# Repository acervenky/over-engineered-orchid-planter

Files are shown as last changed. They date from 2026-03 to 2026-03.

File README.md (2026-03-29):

<div align="center">

# 🌸 Smart Tolumnia Planter V1

### *The Unnecessarily Intelligent Epiphyte Bioreactor*

An intelligent, two-tiered 3D-printed enclosure with an **autonomous Qwen-powered AI agent** that perfectly orchestrates the strict flood-and-bone-dry cycles required by bare-root Tolumnia orchids... because watering plants with a spray bottle is *so* last century.

<br>
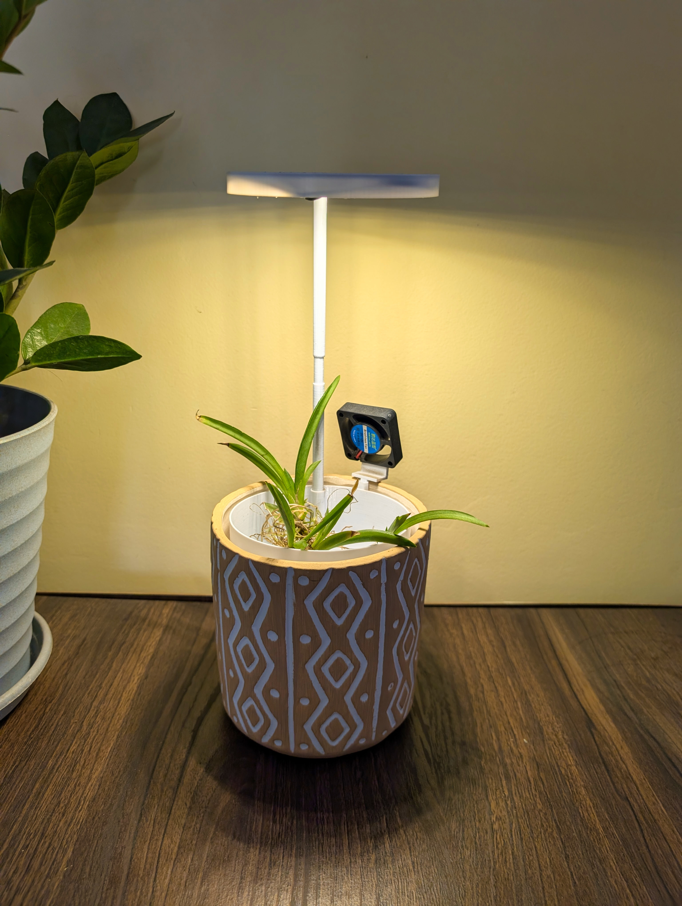
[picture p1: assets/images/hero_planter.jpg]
The Tolumnia Digital Botanist Bioreactor

<p align="center"><i>Note: The brown tips visible on the Tolumnia leaves in the image above are due to long shipping transits, not the setup. The plant recovers once the automated watering loop is established.</i></p>
<br><br>

---

**Part of the *Over Engineered by Venky* Series**

> *Welcome to "Over Engineered by Venky", a growing collection of projects where the solution is gloriously, unapologetically disproportionate to the problem. Need to water a notoriously finicky Tolumnia orchid? Sure, a $10 hardware timer might work. But why not deploy a Pico W, a custom 3D-printed twin-tier reservoir, PWM-controlled micro-climate fans, and a 9-Billion parameter Neural Network that mathematically calculates Vapor Pressure Deficit (VPD) to trigger synthetic flood cycles? Efficiency? Optional. Style points? Mandatory.*

---






</div>

---

## 📖 The Philosophy: Why Tolumnia? Why an AI?

Tolumnia orchids are notoriously difficult to keep alive in a standard home environment. As miniature epiphytes from the Caribbean, they demand a very specific and unforgiving mechanical cycle: their roots must be absolutely drenched in water, and then rapidly, completely dried out. They explicitly abhor sitting in soggy media—hence, keeping them completely **bare root**. 

Doing this manually requires extreme discipline: daily 15-minute drenching sessions followed by ensuring ample airflow so the velamen layer (the spongy epidermis of orchid roots) dries out immediately. Forget for a few days, and they shrivel into dust. Leave them wet overnight, and the roots instantly turn to mush and the plant rots. 

**The Evolution:** This project completely removes human fallibility by creating an enclosed, fully automated micro-environment where these ruthless biological laws are algorithmically enforced by a Local Large Language Model. We aren't just turning a pump on and off; we are simulating the evaporative cycles of the Caribbean using a hyper-advanced "Digital Botanist."

---

## 🆚 The Problem vs. The Over-Engineered Solution

**The Normal Solution:** Buy a $10 programmable timer plug that turns a tiny water pump on for 1 minute every 24 hours, and runs a fan for an hour afterwards. It has no idea if the air is humid, if the roots are actually dry, or if the sun has set. It just blindly pumps.

**The Venky Solution:** A custom 3D-printed two-tiered inner structure sitting inside a premium thermal clay pot. A Raspberry Pi Pico W orchestrates a 5V submersible pump, a high-CRI grow light, and a 40mm micro-fan. The Pico W streams live telemetry over WebSockets to an asynchronous FastAPI Python server. This server queries a local Qwen 9B LLM. The AI cross-references ambient room humidity, temperature, and calculated Vapor Pressure Deficit (VPD) to enforce a mandatory 15-minute root tissue soak, before deciding the exact optimal duration of the aggressive dry cycle.

Because why guess if the roots are dry when a neural network can calculate the exact atmospheric evaporation rate?

---

## 🏗️ Hardware Architecture & The Enclosure

The physical system uses a custom **Two-Tiered 3D Printed Structure** nested inside an **Outer Clay Pot**:

### 1. The Outer Clay Pot
Houses the entire plastic assembly. Provides critical thermal mass and insulation for the water reservoir against extreme room temperatures, preventing the nutrient solution from heating up. It also maintains a clean, premium, natural aesthetic that belies the ridiculous amount of silicon inside it. The entire setup is designed to be completely wire-free from the outside, hiding all messy electronics and routing cables internally through the dual-tier structure for a sleek, living-room-ready look.

### 2. Bottom Tier (The Reservoir)
A 3D-printed inner section holding the nutrient water mixture. 
* Houses a micro submersible 5V water pump.
* Houses a **Capacitive Water Level Sensor** attached to the Pico W. If the water level drops too low, the hardware layer strictly blocks the pump to prevent it from running dry and burning out, regardless of what the AI demands.

### 3. Top Tier (The Orchid Chamber)
A 3D-printed inner basket holding the bare-root orchid. 
* Designed with aggressive, rapid-drainage holes leading straight back down to the reservoir. 
* Mounts the 40mm PWM cooling fan to blast the roots dry.
* Mounts the overhead high-CRI grow light.
* Mounts the ultra-precise **Sensirion SHT41 Temp/Humidity Sensor**, which acts as the "lungs" of the operation.

<div align="center">
  <br>
  Water Flooding Cycle Animation
  <br>
  <i>The 15-Minute Synthetic Ecosystem Flood Triggered by Qwen</i>
  <br><br>
</div>

```mermaid
graph TD
    subgraph Edge ["🌸 Planter Hardware (Raspberry Pi Pico W)"]
        direction TB
        Sensors[SHT41 Temp/Humidity Sensor]
        WaterLevel[Capacitive Water Level Sensor]
        Pump[5V Submersible Pump]
        Fan[40mm Drying Fan]
        Light[Grow Light]
        Pico[MicroPython Firmware]
        Pico -- I2C Reads --> Sensors
        Pico -- GPIO Reads --> WaterLevel
        Pico -- Relay/MOSFET --> Pump
        Pico -- PWM --> Fan
        Pico -- Relay --> Light
    end

    subgraph Server ["🧠 Digital Botanist Local Server"]
        direction TB
        WS[FastAPI Async WebSocket]
        Agent[Qwen 9B LLM Agent via Ollama]
        DB[(Cycle History SQLite)]
        
        WS <--> Agent
        Agent <--> DB
    end

    Pico <-->|Live JSON Telemetry State| WS
    Server -- Dispatch JSON Tool Commands --> WS
```

---

## 🤖 The Autonomous "Botanist" Agent

Unlike a brittle Python script with endless `if/else` statements, the Agent operates on a continuous, biologically aware **OODA Loop (Observe, Orient, Decide, Act)**:

### 1. Perception & Beliefs
The agent constantly monitors the micro-climate via the SHT41. The FastAPI middle-layer mathematically calculates the **Saturation Vapor Pressure (SVP)** and the **Actual Vapor Pressure (AVP)** to derive the true **Vapor Pressure Deficit (VPD)** before handing the context over to Qwen. 

### 2. Reasoning & Planning (The Biological Directives)
Armed with its beliefs, the Qwen 9B LLM enforces strict botanical laws baked directly into its system prompt:
* **The 15-Minute Rule:** A flood cycle is useless if the velamen tissue doesn't have time to absorb it. The AI must structure any pump activation to guarantee a strict 15-minute minimum soak.
* **The Nighttime Veto:** Tolumnias absolutely *cannot* be watered at night, or the temperature drop will cause crown rot. If the roots are bone dry but the sun has set, the AI will actively suppress its own watering urges, logging a delay until sunrise.
* **VPD Cooling:** During heatwaves (>30°C), the AI proactively triggers the 40mm fan to provide cooling drafts independent of the watering cycle, preventing the plant from entering heat dormancy and encouraging early flowering.

### 3. Action (JSON Tool Calling)
The LLM mathematically justifies its plan and outputs a strict JSON array representing Python function executions:
- `{"tool": "trigger_flood", "kwargs": {"duration_minutes": 15}}`: Submerges the roots via the water pump relay.
- `{"tool": "set_fan_speed", "kwargs": {"percent": 100, "duration_minutes": 45}}`: Blasts the roots bone-dry using PWM control.
- `{"tool": "set_grow_light", "kwargs": {"state": "ON"}}`: Controls the synthetic sun.

---

## 📸 Inside the AI's Mind

Because this is a reasoning agent, you don't just get `[INFO] Pump ON`. You get the exact biological reasoning trace logged in real-time. Here's what goes through its head on a dangerously hot afternoon:

```json
[BOTANIST LOG] SHT41 Telemetry: Temp 31.5°C, Humidity 45%. Water Level: OK.
[BOTANIST LOG] Calculated VPD: 1.9 kPa (High).
[QWEN AGENT] PERCEIVE: Extreme Heat Stress. Velamen is likely completely desiccated. It is 14:00 (Daytime) - safe to water. 
[QWEN AGENT] REASONING: Situation Critical - The high VPD (1.9 kPa) is causing rapid transpiration. I must initiate an immediate flood cycle for tissue absorption. Following that, I must aggressively engage the PWM fan to drop the ambient micro-climate temperature through evaporative cooling to prevent heat dormancy.
[QWEN AGENT] PLAN: [{"tool": "trigger_flood", "kwargs": {"duration_minutes": 15}}, {"tool": "set_fan_speed", "kwargs": {"percent": 80, "duration_minutes": 60}}]
[BOTANIST LOG] Dispatching WebSocket tool commands to Pico W -> SUCCESS
```

---

## 🖨️ 3D Printing the Planter

All structural models and STL assemblies for the custom micro-climate bioreactor are provided in the repository. The assembly is specifically engineered to cradle the bare roots securely while guaranteeing zero water-pooling after the pump halts.

* **[Bottom Reservoir (`bottom_reservoir.stl`)](hardware/stls/bottom_reservoir.stl):** Houses the 5V pump and acts as the water reserve. Print with 3+ perimeters to ensure it is 100% watertight.
* **[Top Orchid Chamber (`top_orchid_chamber.stl`)](hardware/stls/top_orchid_chamber.stl):** The aggressively drained upper basket supporting the bare-root setup.
* **[Fan Mount Assembly (`fan_mount_angle.stl` & `fan_mount_clip.stl`)](hardware/stls/fan_mount_angle.stl):** Mechanical brackets used to securely snap the 40mm PWM cooling fan onto the top chamber.
* **[Grow Light Assembly (`grow_light_hood.stl`, `grow_light_support_arm_1.stl`, `grow_light_support_arm_2.stl`)](hardware/stls/grow_light_hood.stl):** Casing and vertical support poles to position a ring-style high-CRI LED halo exactly over the foliage without blocking the SHT41.

---

## 💻 Tech Stack & Software

- **Local Server**: A lightweight `FastAPI` instance running a bidirectional WebSocket endpoint (`/ws/telemetry`).
- **AI Backend**: `Ollama` running locally, utilizing the `qwen2.5:9b` instruct model (or whichever reasoning model fits on your GPU).
- **Firmware**: Custom `MicroPython` script on the Pico W using `uasyncio` to simultaneously poll I2C sensors, manage WebSocket keep-alives, and operate hardware relays.
- **State Persistence**: Minimal `SQLite` architecture storing the historical Timestamped Telemetry, Agent Plans, and Action execution logs so the AI can literally reflect on its past decisions.

---

## 🚀 Installation & Setup

### 1. The Server (Digital Botanist)
You need a machine with Python 3.10+ (preferably with a GPU for Ollama).

```bash
cd server
python -m venv venv
source venv/bin/activate  # Or `venv\Scripts\activate` on Windows
pip install -r requirements.txt
```

**Install Ollama and Pull the Model:**
1. Install [Ollama](https://ollama.com/download) for your OS.
2. Pull the model: `ollama run qwen2.5:9b` (or modify `agent.py` to use a smaller model if needed).

**Run the Server:**
```bash
uvicorn main:app --host 0.0.0.0 --port 8000
```
*Note the IP address of this machine on your local network (e.g., `192.168.1.100`).*

### 2. The Firmware (Pico W)
1. Flash your Raspberry Pi Pico W with the latest [MicroPython firmware](https://micropython.org/download/RPI_PICO_W/).
2. Copy `firmware/config.example.py` to `firmware/config.py`.
3. Edit `config.py` with your WiFi credentials and the IP address of your FastAPI server.
4. Install `uwebsockets` onto the Pico using `mip` or Thonny.
5. Upload `main.py` and `config.py` to the Pico.

### 3. Hardware Wiring (Pin Reference)
- **SHT41 Temp/Humidity (I2C):** SDA -> `GPIO 4`, SCL -> `GPIO 5`
- **Capacitive Water Level:** Signal -> `GPIO 14` (Set to pull LOW when wet)
- **5V Submersible Pump:** Logic MOSFET -> `GPIO 15`
- **Grow Light Relay:** Logic -> `GPIO 16`
- **40mm Fan PWM:** Logic MOSFET -> `GPIO 17`

---

## 💰 Bill of Materials (BOM)

| # | Component | Specs | Qty | Price (Est.) | Notes |
|---|---|---|---|---|---|
| 1 | Raspberry Pi Pico W | RP2040, Wi-Fi | 1 | **₹600** | The sensory edge node |
| 2 | 3D Printed Planter | 2-Tier Inner Core | 1 | **~₹200** (Filament) | Custom STL holding roots and reservoir |
| 3 | Outer Clay Pot | Ceramic | 1 | **₹500** | Thermal mass and premium aesthetics |
| 4 | 5V Submersible Pump | Mini Water Pump | 1 | **₹100** | Synthesizes the 15-min flood cycle |
| 5 | 40mm PWM Fan | 5V DC micro fan | 1 | **₹250** | Forced-air root drying & VPD cooling |
| 6 | Grow Light | LED High-CRI Halo | 1 | **₹700** | Drives photosynthesis |
| 7 | **SHT41 Sensor** | I2C Temp & Humid | 1 | **₹500** | The ultra-precise lungs of the operation |
| 8 | **Capacitive Water Level** | Non-contact | 1 | **₹250** | Prevents catastrophic dry-running |
| 9 | Logic Level MOSFETs | IRLZ44N & Relays | 3 | **₹50 ea** | High-current switching for pump/fan/light |
| 10| Silicone Tubing | 6mm/8mm | 1M | **₹150** | Water routing from pump to top tier |

> *Total Estimated Hardware Cost: **~₹3,400*** (Excluding server hardware, as Ollama runs on your existing PC)

<div align="center">

**Over Engineered with 💚 by Venky**

*Because manual watering is a single point of failure.*

</div>

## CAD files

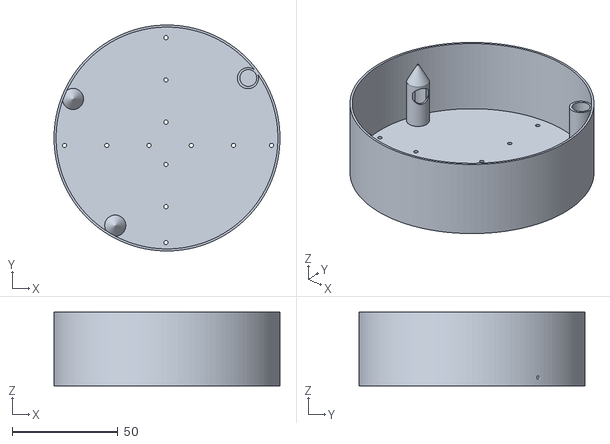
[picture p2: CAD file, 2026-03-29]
hardware/stls/top_orchid_chamber.stl
107.0 x 107.0 x 35.0

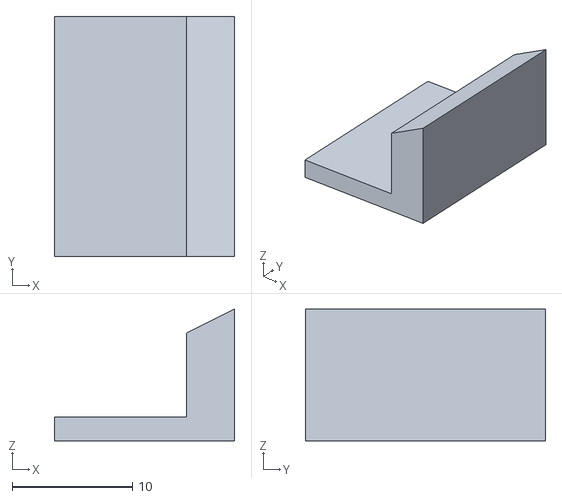
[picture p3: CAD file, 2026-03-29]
hardware/stls/fan_mount_angle.stl
15.0 x 20.0 x 11.0

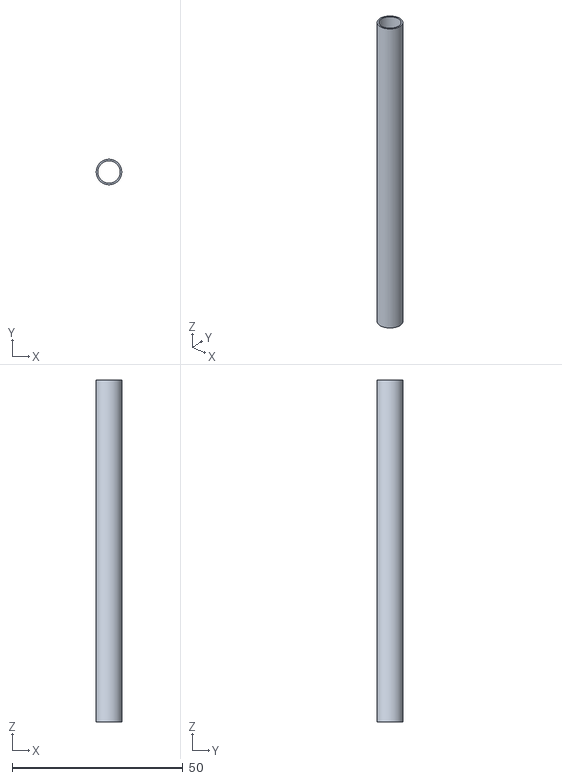
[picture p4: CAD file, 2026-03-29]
hardware/stls/grow_light_support_arm_1.stl
7.50 x 7.50 x 100.0

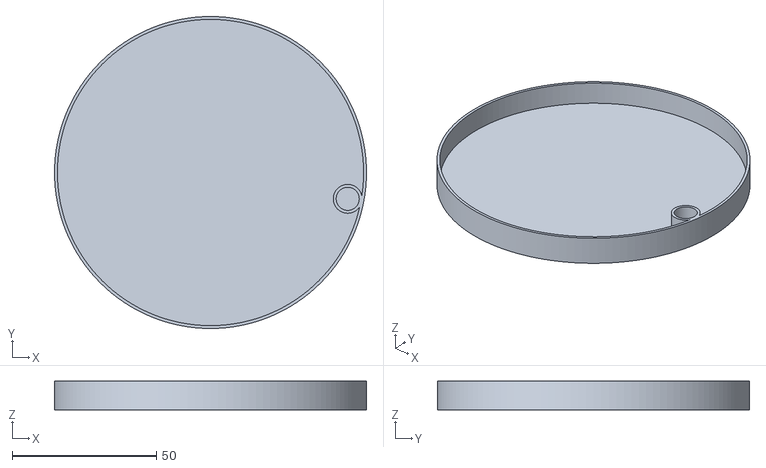
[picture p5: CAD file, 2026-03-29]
hardware/stls/grow_light_hood.stl
108.0 x 108.0 x 10.0

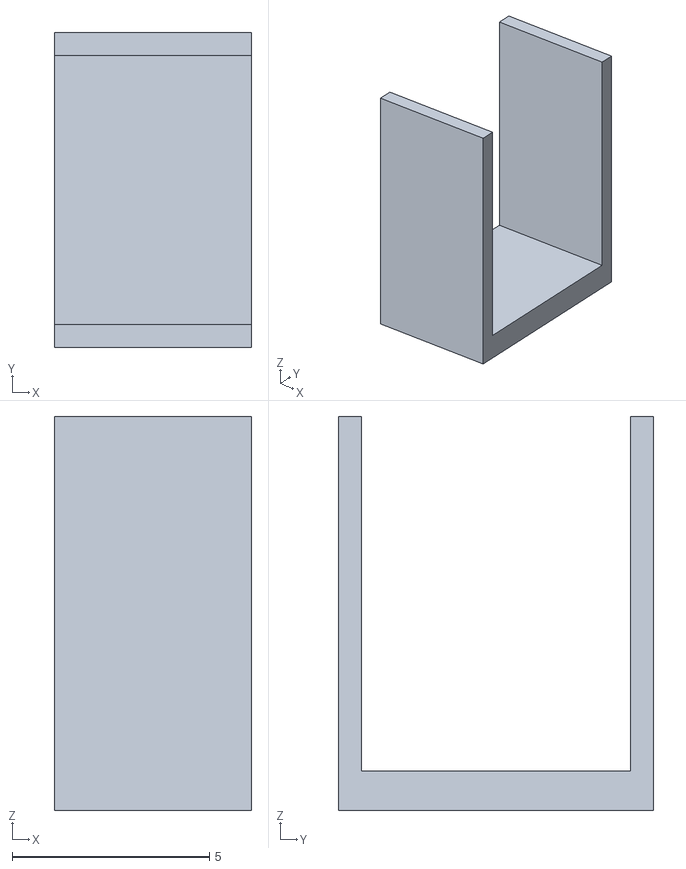
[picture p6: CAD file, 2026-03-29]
hardware/stls/fan_mount_clip.stl
5.00 x 8.00 x 10.0

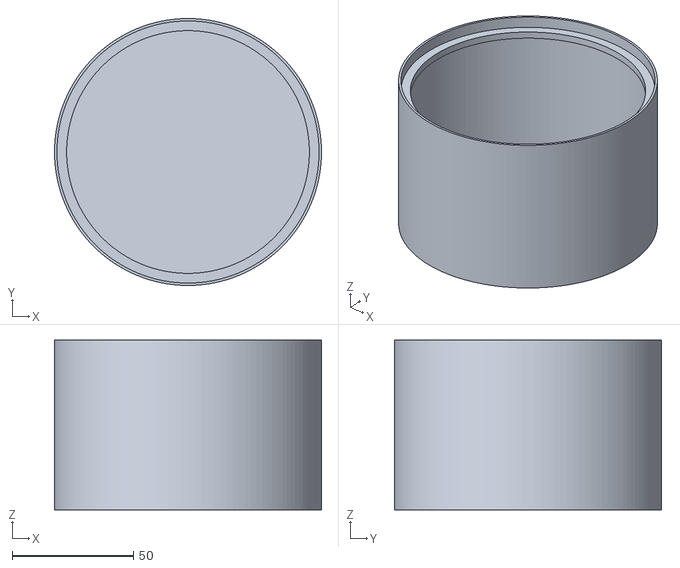
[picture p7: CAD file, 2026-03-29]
hardware/stls/bottom_reservoir.stl
110.0 x 110.0 x 70.0

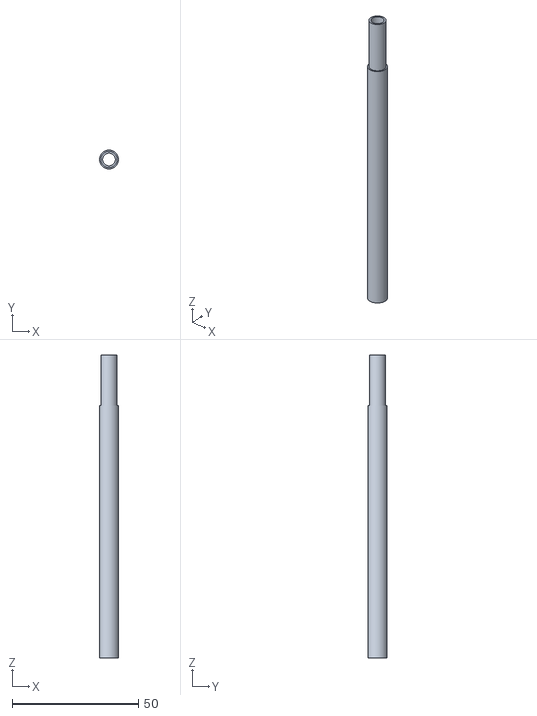
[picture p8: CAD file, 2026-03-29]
hardware/stls/grow_light_support_arm_2.stl
7.50 x 7.50 x 120.0

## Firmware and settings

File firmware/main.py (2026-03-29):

import network
import uasyncio as asyncio
import json
import machine
import time
import select
import config

# Initialize Watchdog Timer (8.3s max on Pico, we'll feed it regularly)
wdt = machine.WDT(timeout=8000)

try:
    import uwebsockets.client as websockets
except ImportError:
    websockets = None
    print("WARNING: uwebsockets missing. Please install it.")

# --- HARDWARE PIN SETUP ---
# SHT41 Temp/Humidity (I2C)
i2c = machine.I2C(0, sda=machine.Pin(4), scl=machine.Pin(5), freq=400000)

# Capacitive Water Level Sensor (Active Low/High depending on the specific module)
# Assuming a generic module that pulls LOW when wet
WATER_LEVEL_PIN = machine.Pin(14, machine.Pin.IN, machine.Pin.PULL_UP)

# Relays / MOSFET logic pins
PUMP_PIN = machine.Pin(15, machine.Pin.OUT)
LIGHT_PIN = machine.Pin(16, machine.Pin.OUT)

# 40mm PWM Fan
FAN_PIN = machine.PWM(machine.Pin(17))
FAN_PIN.freq(1000)
FAN_PIN.duty_u16(0)

class BotanistNode:
    def __init__(self):
        self.wlan = network.WLAN(network.STA_IF)
        self.ws = None # In production, use `uwebsockets` or `asyncio.stream`
        self.pump_task = None
        self.fan_task = None
        self.last_water_ms = time.ticks_ms()
        
    async def connect_wifi(self):
        self.wlan.active(True)
        if not self.wlan.isconnected():
            print(f"Connecting to {config.WIFI_SSID}...")
            self.wlan.connect(config.WIFI_SSID, config.WIFI_PASS)
            
            # Wait for connection with timeout
            attempts = 0
            while not self.wlan.isconnected() and attempts < 15:
                wdt.feed() # Keep WDT happy while connecting
                await asyncio.sleep(1)
                attempts += 1
            
            if not self.wlan.isconnected():
                print("WiFi connection failed (timeout).")
                return False
                
        print("WiFi Connected. IP:", self.wlan.ifconfig()[0])
        return True

    async def connect_websocket(self):
        """
        Connects to the FastAPI WS server.
        Note: requires uwebsockets to be installed via mip.
        """
        if websockets is None:
            print("WebSocket client not available. Cannot connect.")
            return False
            
        token = getattr(config, 'WS_TOKEN', '')
        url_with_token = f"{config.WS_SERVER_URL}?token={token}"
        print(f"Connecting to {url_with_token}...")
        try:
            self.ws = websockets.connect(url_with_token)
            print("WebSocket Connected!")
            return True
        except Exception as e:
            print(f"WebSocket connection failed: {e}")
            self.ws = None
            return False

    def calc_crc8(self, data: bytes) -> int:
        """Calculates CRC-8 for SHT4x sensors"""
        crc = 0xFF
        for idx in range(2):
            crc ^= data[idx]
            for _ in range(8):
                if crc & 0x80:
                    crc = (crc << 1) ^ 0x31
                else:
                    crc <<= 1
        return crc & 0xFF

    async def read_sht41(self) -> tuple:
        """
        Reads Temperature and Humidity directly via I2C for the SHT41 sensor.
        0xFD is the high precision measurement command.
        """
        try:
            i2c.writeto(0x44, b'\xFD')
            await asyncio.sleep_ms(10) # Give sensor time to measure
            data = i2c.readfrom(0x44, 6)
            
            # Check CRC
            if self.calc_crc8(data[0:2]) != data[2] or self.calc_crc8(data[3:5]) != data[5]:
                print("SHT41 CRC Error!")
                return (None, None)
            
            temp_raw = (data[0] << 8) | data[1]
            hum_raw = (data[3] << 8) | data[4]
            
            temp_c = -45.0 + (175.0 * temp_raw / 65535.0)
            humidity = -6.0 + (125.0 * hum_raw / 65535.0)
            
            # Clamp humidity
            humidity = max(0.0, min(100.0, humidity))
            
            return round(temp_c, 2), round(humidity, 2)
        except Exception as e:
            print("SHT41 read error:", e)
            return (25.0, 50.0) # Safe fallback

    async def telemetry_loop(self):
        """Streams real-time environment data to the FastAPI server."""
        while True:
            temp, hum = await self.read_sht41()
            
            # Read capacitive sensor (assumes LOW = wet/water present)
            water_ok = (WATER_LEVEL_PIN.value() == 0)
            
            # Send payload if we got valid sensor readings
            if temp is not None and hum is not None:
                payload = {
                    "temp_c": temp,
                    "humidity": hum,
                    "water_level_ok": water_ok,
                }
                
                print("Sending Telemetry ->", payload)
                
                # If WS is connected, send payload
                if self.ws:
                    try:
                        self.ws.send(json.dumps(payload))
                    except Exception as e:
                        print(f"WS Send Error: {e}")
                        self.ws = None # Force reconnect
                
            await asyncio.sleep(60) # 60-second sampling rate

    async def command_loop(self):
        """Listens for tool calls from the AI Agent."""
        while True:
            if self.ws:
                try:
                    # Use select.poll to check if socket has data before calling blockingly
                    poller = select.poll()
                    poller.register(self.ws.sock, select.POLLIN)
                    
                    # poll with 0 timeout (non-blocking)
                    res = poller.poll(0)
                    if res:
                        cmd_str = self.ws.recv() 
                        if cmd_str:
                            cmd = json.loads(cmd_str)
                            self.handle_command(cmd)
                except Exception as e:
                    # Connection drops or timeout
                    print(f"WS Recv Error/Timeout: {e}")
                    self.ws = None
            
            await asyncio.sleep(1)
            
    def handle_command(self, cmd: dict):
        tool = cmd.get("tool")
        kwargs = cmd.get("kwargs", {})
        
        print(f"Executing: {tool} with args {kwargs}")
        
        if tool == "trigger_flood":
            self.last_water_ms = time.ticks_ms()
            dur_mins = kwargs.get("duration_minutes", 15)
            if self.pump_task:
                self.pump_task.cancel()
            self.pump_task = asyncio.create_task(self.run_pump(dur_mins))
            
        elif tool == "set_fan_speed":
            speed_pct = kwargs.get("percent", 0)
            dur_mins = kwargs.get("duration_minutes", 0)
            if self.fan_task:
                self.fan_task.cancel()
            self.fan_task = asyncio.create_task(self.run_fan(speed_pct, dur_mins))
            
        elif tool == "set_grow_light":
            state = kwargs.get("state", "OFF")
            LIGHT_PIN.value(1 if state == "ON" else 0)
            print("Light toggled:", state)

    async def run_pump(self, duration_mins: int):
        try:
            # Failsafe check: if WATER_LEVEL_PIN is HIGH (1), it means it's not wet (assuming LOW = wet)
            if WATER_LEVEL_PIN.value() != 0:
                print("[HW] FAILSAFE ENGAGED: PUMP BLOCKED - Water level low!")
                return
            
            # Hardcap pump run time
            safe_duration = min(duration_mins, 30)
            if safe_duration != duration_mins:
                print(f"[HW] WARNING: LLM requested {duration_mins}m. Capping to {safe_duration}m!")
            
            print(f"[HW] PUMP ON for {safe_duration} mins")
            PUMP_PIN.value(1)
            
            # Wait for duration (split into 1-sec sleeps to feed watchdog)
            for _ in range(safe_duration * 60):
                wdt.feed()
                # Check failsafe continuously
                if WATER_LEVEL_PIN.value() != 0:
                    print("[HW] FAILSAFE ENGAGED MID-CYCLE: PUMP BLOCKED - Water level low!")
                    break
                await asyncio.sleep(1)
                
        except asyncio.CancelledError:
            print("[HW] PUMP task cancelled (Duplicate command received)")
        finally:
            PUMP_PIN.value(0)
            print("[HW] PUMP OFF - Flood cycle complete")

    async def run_fan(self, speed_percent: int, duration_mins: int):
        try:
            print(f"[HW] FAN ON at {speed_percent}% for {duration_mins} mins")
            duty = int((speed_percent / 100.0) * 65535)
            FAN_PIN.duty_u16(duty)
            
            if duration_mins > 0:
                await asyncio.sleep(duration_mins * 60)
        except asyncio.CancelledError:
            print("[HW] FAN task cancelled (Duplicate command received)")
        finally:
            FAN_PIN.duty_u16(0)
            print("[HW] FAN OFF - Drying/Cooling complete")

async def offline_fallback_loop(node):
    """Fallback timer if server drops offline. Waters every 36h for 15m."""
    WATER_INTERVAL_MS = 36 * 60 * 60 * 1000 # 36 hours
    
    while True:
        if node.ws is None:
            now = time.ticks_ms()
            if time.ticks_diff(now, node.last_water_ms) > WATER_INTERVAL_MS:
                print("[FALLBACK] Server offline > 36h. Running emergency flood.")
                node.handle_command({"tool": "trigger_flood", "kwargs": {"duration_minutes": 15}})
                
        await asyncio.sleep(60)

async def main():
    node = BotanistNode()
    
    # Launch parallel generic tasks
    asyncio.create_task(node.telemetry_loop())
    asyncio.create_task(node.command_loop())
    asyncio.create_task(offline_fallback_loop(node))
    
    # Keep the main loop alive and manage connection state
    while True:
        wdt.feed()  # Feed watchdog
        if not node.wlan.isconnected():
            print("WiFi not connected. Reconnecting...")
            await node.connect_wifi()
            
        if node.wlan.isconnected() and node.ws is None:
            await node.connect_websocket()

        await asyncio.sleep(1)

if __name__ == "__main__":
    try:
        print("Starting Botanist Edge Node...")
        asyncio.run(main())
    except KeyboardInterrupt:
        # Safe shutdown state
        PUMP_PIN.value(0)
        LIGHT_PIN.value(0)
        FAN_PIN.duty_u16(0)
        print("\nShutdown complete. All relays disabled.")

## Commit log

2026-03-29 Project baseline
    [bottom_reservoir.stl, fan_mount_angle.stl, fan_mount_clip.stl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]
2026-03-29 docs: add estimated hardware costs to the bill of materials in README.md
